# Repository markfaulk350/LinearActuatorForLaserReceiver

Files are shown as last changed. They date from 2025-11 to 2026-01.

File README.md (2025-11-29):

# Linear Actuator For Laser Receiver

# Todo
- See if we can use the DF Robot Voice Recognition to controll the whole thing. Look at the [pre-programmed keywords](https://wiki.dfrobot.com/SKU_SEN0539-EN_Gravity_Voice_Recognition_Module_I2C_UART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) to see what would work best.
- Get 4x M3 bolts for the motor. The depth is 4.5mm (0.17 in), so add the thickness of the plate. M3 x 0.5 x 8mm is best for a 0.2in plate.
- Get 3x M3 x 0.5 x 16mm bolts for the lead screw flange nut. Model the carriage so they can thread into the plastic. The flange is 0.19in thick so .6 in or 16mm is probably good. 12mm long might work but just barely, try 16mm at lowes.
- Order limit switches
- Order a linear rail. Or see if we can use the 2040 instead with a 3d printed solution.
- Order 2mm right angle pcb connector and male connector w wires
- Maybe make your own M18 adapter and put all the electronics inside it, boost converter, fuse, arduino, buck converter for arduino, etc.
- Order or make a 5mm to 3/8 coupler
- 3d print a qd mount for the laser receiver

## Custom Sensor Array vs Standard Laser Receiver on Linear Actuator
A Custom CCD or photodiode array is going to be too expensive, time consuming, and it might not work with every laser. 

On the Job, we are already moving the stick up and down, and tilting it to get the laser receiver to beep.

I propose we just hold the stick still, and have a linear actuator move the standard laser receiver until it beeps. We can tie into the laser receivers speaker wires and use that to position it perfectly. Once it's positioned, we can give the user the measurement.

### Linear Actuator
### Pros
- Cheap
- Simple to program
- Technology already exists
- Can be expanded to any length cheaply
- Can mount any laser receiver

### Cons
- Bulky
- Heavier
- Requires more power
- The physical size of the laser receiver affects the total scan area. And user needs to set the max extension so that it doesn't crash the laser receiver into the enclosure.
- Scanning is slower. 1ft per second is acceptable
  - Scanning speed largely depends on how quickly the laser receiver can detect the laser. 
- The UI is more complicated. (Calibrate, Jog, "Home", Scan)
- Different laser receivers have different speakers and signals
- If the laser receiver moves up and down, we either need to listen for the (fast, solid, slow) beeps using a microphone, or tap into the speaker wires.
- If we tap into the speaker wires, we will need to make a little radio to transmit the speaker signals to our esp32. The laser receiver will be moving up and down, we cant use a wire, it would snag or break.

# Build requirements
- Needs to scan quickly. 1ft per second is a good speed.
- Needs to move a 300g laser reeciver up and down.
- No creep. If bumped, powered off, etc. Belt drive probably wont work.
- 2 to 3 ft scan area
- Total weight under 5 pounds. Loose requirement.
- Needs to work in a dusty, hot environment.
- Encoder on stepper motor for exact position
- Maybe boost convertor for higher speeds

# Laser Receiver Dimensions
- Topcon LS-80L (NEW Model)
  - x in (Tall) | x in (Wide) | x in (Thick) | x grams (Weight)
- Topcon LS-70B (OLD Model)
  - 6.5 in (Tall) | 3 in (Wide) | 1.05 in (Thick) | 220 grams (Weight)

# Parts List
- $71 | [StepperOnline | ESS17-04](https://www.omc-stepperonline.com/ess-series-0-48nm-68oz-in-nema-17-integrated-closed-loop-stepper-servo-motor-24-36vdc-1000cpr-ess17-04)
  - [3D Model .IGS](https://www.omc-stepperonline.com/index.php?route=product/product/get_file&file=1265/ESS17-04.IGS)
  - Input Voltage: 24 - 36VDC
  - Weight: 419g
  - [SpecSheet](file:///Users/markfaulkner/Downloads/ESS17-04_07_Manual.pdf)
- $83 | [M18 HIGH OUTPUT CP3.0](https://www.milwaukeetool.com/products/48-11-1835)
  - Weight: 595g
- $8 | [M18 Adapter | Amazon](https://a.co/d/7E8KwFV)
  - Weight: 80g
- $57 | [300W Boost Converter | I7C4W008A120V-001-R | Digikey](https://www.digikey.com/en/products/detail/tdk-lambda/I7C4W008A120V-001-R/11697408)
  - Weight: 25g, 1.5 x 1.5 x 0.5 inches
  - Output Voltage: 9.6 to 48V
  - [SpecSheet](https://product.tdk.com/en/search/power/switching-power/dc-dc-converter/info?part_no=i7C4W008A120V-001-R)
- $40 | [Roton Torqspline Lead Screw, 3/8 X 1.000](https://www.roton.com/product/torqspline-steel-screw-right-60998/)
  - Weight: 368g for all 36 inches
- $20 | [Roton Torqspline Flange Nut, 3/8 X 1.000, RH, Plastic](https://www.roton.com/product/torqspline-plastic-flange-nut-right-92054/)
  - Weight: na
- $40 | [2x 2040 Aluminum V Slot 4ft | Amazon](https://a.co/d/5IGCPNE)
  - Weight: na
- $7 | [R6-2RS Bearings 3/8 ID x 7/8 OD x 9/32 | Amazon](https://a.co/d/5ckjm9j)
  - Weight: na
- $ | []()
  - Weight: na
 
## Small electronics parts list
- 47k R + 10k R Voltage divider
- 1x 0.15uf [Ceramic Capacitor](https://a.co/d/4Orx2Qe)
- [MP1584EN DC-DC Buck Converter](https://a.co/d/amErUwB)

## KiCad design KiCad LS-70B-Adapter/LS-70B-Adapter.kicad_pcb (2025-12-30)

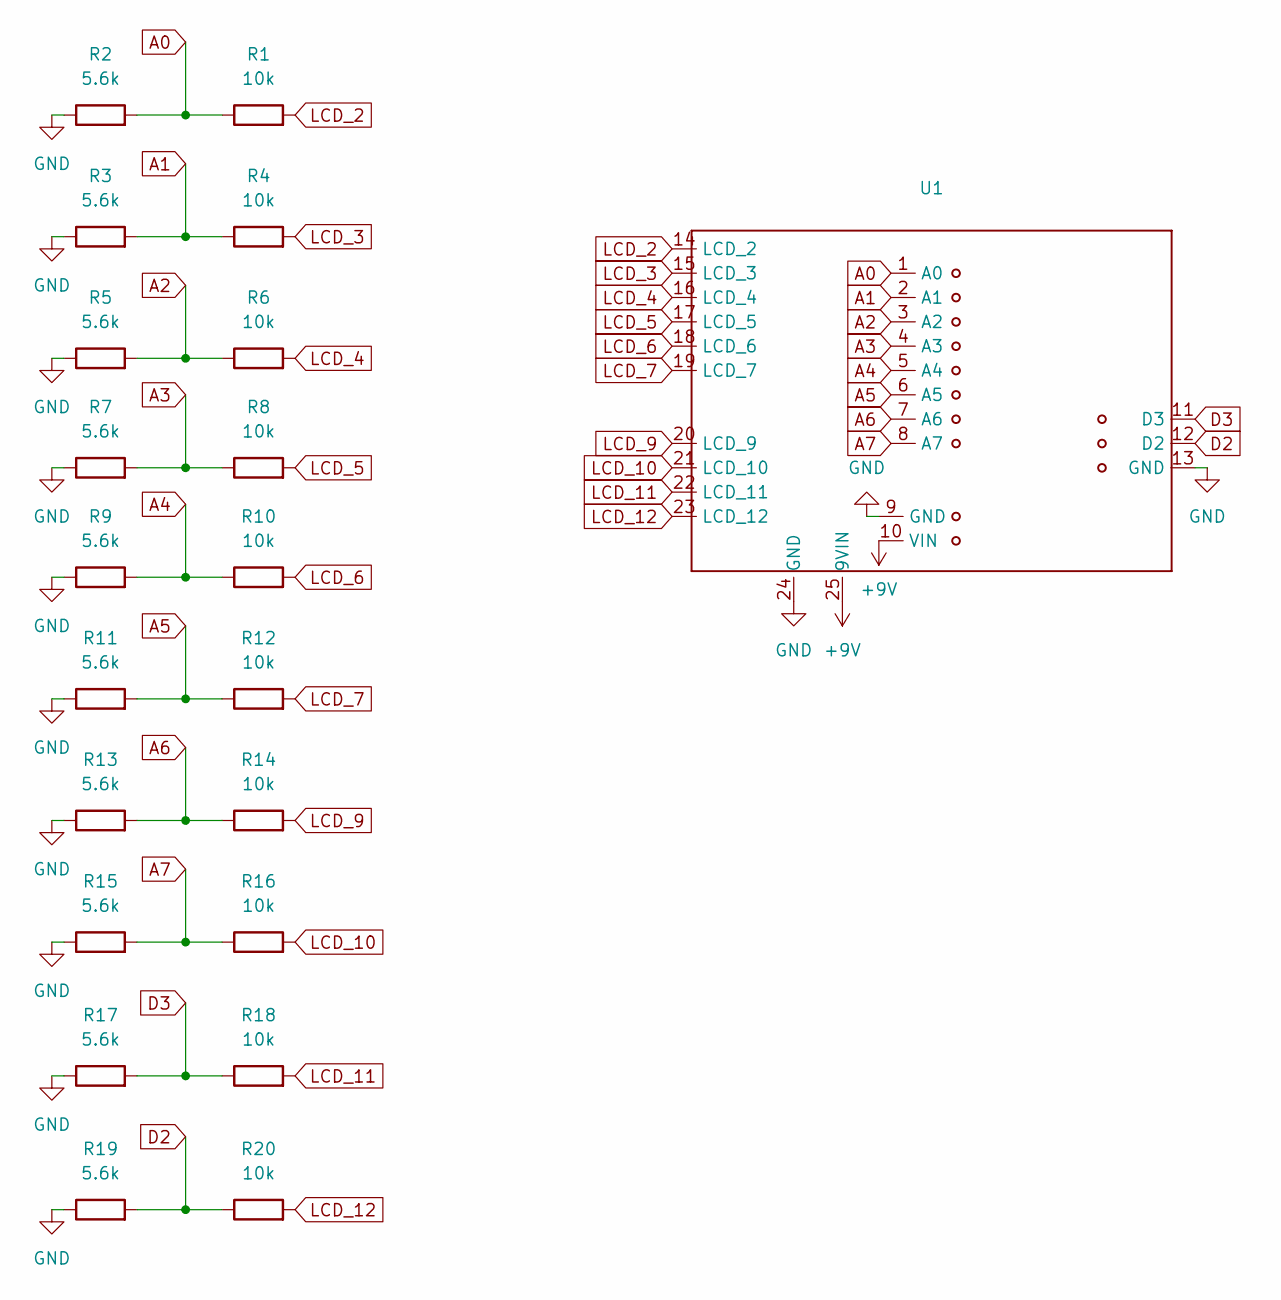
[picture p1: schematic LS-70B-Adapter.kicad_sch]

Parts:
R1, R4, R6, R8, R10, R12, R14, R16, R18, R20: 10k; R_0805_2012Metric_Pad1.20x1.40mm_HandSolder
R2, R3, R5, R7, R9, R11, R13, R15, R17, R19: 5.6k; R_0805_2012Metric_Pad1.20x1.40mm_HandSolder
U1: LS70B-Adapter

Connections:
+9V: U1.10 (VIN), U1.25 (9VIN)
A0: R1.1, R2.2, U1.1 (A0)
A1: R3.2, R4.1, U1.2 (A1)
A2: R5.2, R6.1, U1.3 (A2)
A3: R7.2, R8.1, U1.4 (A3)
A4: R9.2, R10.1, U1.5 (A4)
A5: R11.2, R12.1, U1.6 (A5)
A6: R13.2, R14.1, U1.7 (A6)
A7: R15.2, R16.1, U1.8 (A7)
D2: R19.2, R20.1, U1.12 (D2)
D3: R17.2, R18.1, U1.11 (D3)
GND: R2.1, R3.1, R5.1, R7.1, R9.1, R11.1, R13.1, R15.1, R17.1, R19.1, U1.9 (GND), U1.13 (GND), U1.24 (GND)
LCD_2: R1.2, U1.14 (LCD_2)
LCD_3: R4.2, U1.15 (LCD_3)
LCD_4: R6.2, U1.16 (LCD_4)
LCD_5: R8.2, U1.17 (LCD_5)
LCD_6: R10.2, U1.18 (LCD_6)
LCD_7: R12.2, U1.19 (LCD_7)
LCD_9: R14.2, U1.20 (LCD_9)
LCD_10: R16.2, U1.21 (LCD_10)
LCD_11: R18.2, U1.22 (LCD_11)
LCD_12: R20.2, U1.23 (LCD_12)

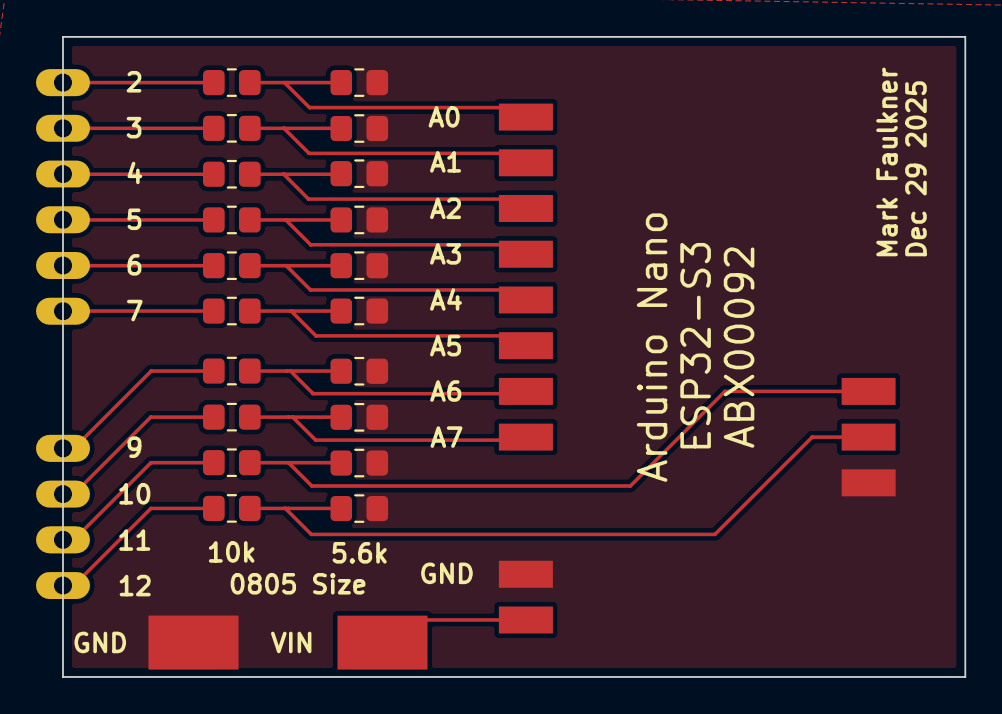
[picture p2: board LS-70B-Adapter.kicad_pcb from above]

Board: 2 copper layers, 50.1 x 35.6 mm, 21 parts (0 on the bottom side), 22 nets.

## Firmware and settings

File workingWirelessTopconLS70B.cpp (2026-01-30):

#include <Arduino.h>
#include <WiFi.h>
#include <WebServer.h>
#include <ArduinoJson.h>

WebServer server(80);

const char* ssid = "Topcon Laser";
const char* password = "12345678";

// Global transition counters — updated after each capture
int transitions_UP4 = 0;
int transitions_UP3 = 0;
int transitions_UP2 = 0;
int transitions_UP1 = 0;
int transitions_CEN = 0;
int transitions_DN1 = 0;
int transitions_DN2 = 0;
int transitions_DN3 = 0;
int transitions_DN4 = 0;
int transitions_ARR = 0;

// ─────────────────────────────────────────────
// Pin definitions
// ─────────────────────────────────────────────
constexpr int UP_BAR_4    = A2;
constexpr int UP_BAR_3    = A3;
constexpr int UP_BAR_2    = A1;
constexpr int UP_BAR_1    = A4;
constexpr int CENTER_BAR  = A5;
constexpr int DOWN_BAR_1  = A6;
constexpr int DOWN_BAR_2  = A7;
constexpr int DOWN_BAR_3  =  2;
constexpr int DOWN_BAR_4  =  3;
constexpr int TOP_ARROW   = A0;

constexpr int CAPTURE_DURATION_MS = 30;
constexpr int SAMPLE_INTERVAL_US  = 20;
constexpr int MAX_SAMPLES = 4000;

// One array per channel
uint8_t s_UP4[MAX_SAMPLES];
uint8_t s_UP3[MAX_SAMPLES];
uint8_t s_UP2[MAX_SAMPLES];
uint8_t s_UP1[MAX_SAMPLES];
uint8_t s_CEN[MAX_SAMPLES];
uint8_t s_DN1[MAX_SAMPLES];
uint8_t s_DN2[MAX_SAMPLES];
uint8_t s_DN3[MAX_SAMPLES];
uint8_t s_DN4[MAX_SAMPLES];
uint8_t s_ARR[MAX_SAMPLES];

// ─────────────────────────────────────────────
// Count number of transitions (0→1 or 1→0)
// ─────────────────────────────────────────────
int countTransitions(const uint8_t data[], uint32_t len) {
  if (len < 2) return 0;

  int flips = 0;
  uint8_t prev = data[0];

  for (uint32_t i = 1; i < len; i++) {
    if (data[i] != prev) {
      flips++;
      prev = data[i];
    }
  }

  return flips;
}

// ─────────────────────────────────────────────
// HTML: 9 horizontal bars stacked vertically (UP4 top → DN4 bottom)
// No labels, grey by default, green when active (transitions > 4)
// Updates every 200 ms
// ─────────────────────────────────────────────
const char html[] PROGMEM = R"rawliteral(
<!DOCTYPE html>
<html lang="en">
<head>
  <meta charset="UTF-8">
  <meta name="viewport" content="width=device-width, initial-scale=1.0">
  <title>Laser Receiver</title>
  <style>
    body { margin:0; height:100vh; background:#111; display:flex; justify-content:center; align-items:center; }
    .container { height:80vh; width:300px; display:flex; flex-direction:column; gap:4px; }
    .bar { flex:1; background:#444; border-radius:6px; transition:background 0.1s; }
    .bar.active { background:#3eff51; }
  </style>
</head>
<body>
  <div class="container">
    <div class="bar" id="bar-UP4"></div>
    <div class="bar" id="bar-UP3"></div>
    <div class="bar" id="bar-UP2"></div>
    <div class="bar" id="bar-UP1"></div>
    <div class="bar" id="bar-CEN" style="border: 2px solid red;"></div>
    <div class="bar" id="bar-DN1"></div>
    <div class="bar" id="bar-DN2"></div>
    <div class="bar" id="bar-DN3"></div>
    <div class="bar" id="bar-DN4"></div>
  </div>

  <script>
    const bars = {
      "UP4": document.getElementById("bar-UP4"),
      "UP3": document.getElementById("bar-UP3"),
      "UP2": document.getElementById("bar-UP2"),
      "UP1": document.getElementById("bar-UP1"),
      "CEN": document.getElementById("bar-CEN"),
      "DN1": document.getElementById("bar-DN1"),
      "DN2": document.getElementById("bar-DN2"),
      "DN3": document.getElementById("bar-DN3"),
      "DN4": document.getElementById("bar-DN4")
    };

    function update() {
      fetch('/data')
        .then(r => r.json())
        .then(data => {
          Object.keys(data).forEach(key => {
            if (bars[key]) {
              if (data[key] > 4) {
                bars[key].classList.add('active');
              } else {
                bars[key].classList.remove('active');
              }
            }
          });
        })
        .catch(e => console.error(e));
    }

    update();
    setInterval(update, 50);
  </script>
</body>
</html>
)rawliteral";

// ─────────────────────────────────────────────
void setup() {
  Serial.begin(2000000);
  delay(200);

  pinMode(UP_BAR_4,   INPUT);
  pinMode(UP_BAR_3,   INPUT);
  pinMode(UP_BAR_2,   INPUT);
  pinMode(UP_BAR_1,   INPUT);
  pinMode(CENTER_BAR, INPUT);
  pinMode(DOWN_BAR_1, INPUT);
  pinMode(DOWN_BAR_2, INPUT);
  pinMode(DOWN_BAR_3, INPUT);
  pinMode(DOWN_BAR_4, INPUT);
  pinMode(TOP_ARROW,  INPUT);

  WiFi.softAP(ssid, password);
  Serial.print("Hotspot: ");
  Serial.print(ssid);
  Serial.print(" | IP: ");
  Serial.println(WiFi.softAPIP());

  server.on("/", []() {
    server.send_P(200, "text/html", html);
  });

  server.on("/data", []() {
    JsonDocument doc;
    doc["UP4"] = transitions_UP4;
    doc["UP3"] = transitions_UP3;
    doc["UP2"] = transitions_UP2;
    doc["UP1"] = transitions_UP1;
    doc["CEN"] = transitions_CEN;
    doc["DN1"] = transitions_DN1;
    doc["DN2"] = transitions_DN2;
    doc["DN3"] = transitions_DN3;
    doc["DN4"] = transitions_DN4;

    String json;
    serializeJson(doc, json);
    server.send(200, "application/json", json);
  });

  server.begin();
}

// ─────────────────────────────────────────────
void loop() {
  server.handleClient();

  static uint32_t lastStart = 0;
  if (millis() - lastStart < 100) return;  // capture every 0.1 second
  lastStart = millis();

  uint32_t tStart = micros();
  uint32_t tEnd   = tStart + CAPTURE_DURATION_MS * 1000UL;

  uint32_t count = 0;
  uint32_t nextSampleTime = tStart;

  while (micros() < tEnd && count < MAX_SAMPLES) {
    while (micros() < nextSampleTime) {}  // wait

    s_UP4[count] = digitalRead(UP_BAR_4);
    s_UP3[count] = digitalRead(UP_BAR_3);
    s_UP2[count] = digitalRead(UP_BAR_2);
    s_UP1[count] = digitalRead(UP_BAR_1);
    s_CEN[count] = digitalRead(CENTER_BAR);
    s_DN1[count] = digitalRead(DOWN_BAR_1);
    s_DN2[count] = digitalRead(DOWN_BAR_2);
    s_DN3[count] = digitalRead(DOWN_BAR_3);
    s_DN4[count] = digitalRead(DOWN_BAR_4);
    s_ARR[count] = digitalRead(TOP_ARROW);

    count++;
    nextSampleTime += SAMPLE_INTERVAL_US;
  }

  // Update global transition counts
  transitions_UP4 = countTransitions(s_UP4, count);
  transitions_UP3 = countTransitions(s_UP3, count);
  transitions_UP2 = countTransitions(s_UP2, count);
  transitions_UP1 = countTransitions(s_UP1, count);
  transitions_CEN = countTransitions(s_CEN, count);
  transitions_DN1 = countTransitions(s_DN1, count);
  transitions_DN2 = countTransitions(s_DN2, count);
  transitions_DN3 = countTransitions(s_DN3, count);
  transitions_DN4 = countTransitions(s_DN4, count);
  transitions_ARR = countTransitions(s_ARR, count);
}

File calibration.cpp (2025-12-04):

// This code homes, goes up to x then steps down 4 steps (0.01in) at a time logging the current Beep status of OFF, FAST, SOLID, SLOW
// This code is used as a referece point for testing other code.
// This also tells us the range of each area of the sensor on the laser receiver

#include <AccelStepper.h>

// ───── Stepper Motor ─────
#define MF_PLUS_PIN 11        // for alarm clearing
#define PULSE_PIN 12
#define DIR_PIN   13
#define ALARM_PIN 14

#define PULSES_PER_REVOLUTION 400

// ───── POSITIONS (hard-coded in inches) ─────
const long POS_HOME     = 0;                                 // 0 inches
const long POS_MIDDLE   = 17L * PULSES_PER_REVOLUTION;       // 17 inches
const long POS_FAR      = 34L * PULSES_PER_REVOLUTION;       // 34 inches
const long ONE_INCH     = 1L  * PULSES_PER_REVOLUTION;       // 1 inch step

// ───── Motor Speed ─────
const long MAX_SPEED_INCHES_PER_SECOND = 6L;
const long MAX_ACCELERATION_PULSES_PER_SECOND = 60L;

const int PIEZO_PIN = 1;
const int SAMPLE_RATE_MS = 5;
const int WINDOW_SIZE = 250 / SAMPLE_RATE_MS;  // 50 samples

int buffer[WINDOW_SIZE];
int idx = 0;
unsigned long last = 0;


AccelStepper stepper(AccelStepper::DRIVER, PULSE_PIN, DIR_PIN);

void setup() {
  Serial.begin(2000000);
  analogReadResolution(12);

  Serial.println("=== RANGE TEST STARTING ===");

  pinMode(ALARM_PIN, INPUT_PULLUP);
  pinMode(MF_PLUS_PIN, OUTPUT);

  // Initialize stepper
  stepper.setMaxSpeed(MAX_SPEED_INCHES_PER_SECOND * PULSES_PER_REVOLUTION);
  stepper.setAcceleration(MAX_ACCELERATION_PULSES_PER_SECOND * PULSES_PER_REVOLUTION);
  stepper.setCurrentPosition(POS_HOME);  // Assume we start at home

 // This will reverse at 1 inch per second and Home automatically. You can comment this out and call it manually if you want using a voice command
  Serial.println("=== HOMING BY STALLING ===");
  homeByStall();

  delay(5000);

  // Move to 34 inches;
  Serial.println("=== MOVE TO 34 IN ===");
  safeMoveTo(25L * PULSES_PER_REVOLUTION);

  delay(5000);

  scanDown();

  Serial.println("=== FINISHED ===");

}

void safeMoveTo(long target) {
  target = constrain(target, POS_HOME, POS_FAR);  // Hard soft limits
  stepper.moveTo(target);
  while (stepper.distanceToGo() != 0) stepper.run();
}


void instantStop() {
  Serial.println("EMERGENCY STOP!");

  long currentPos = stepper.currentPosition();        // Save the exact position

  // Cancel motion instantly but preserve real position
  stepper.setCurrentPosition(currentPos);     // Keep the real position we just saved
  stepper.moveTo(currentPos);                 // Cancel any remaining travel
  stepper.setSpeed(0);                        // Stop generating pulses

  Serial.println("Motor stopped — position preserved for distance calc");


  long stepsFromCenter = currentPos - 6800;           // Subtract 6800 steps aka 17 inches
  float inchesFromCenter = (float)stepsFromCenter / 400.0;  // Convert to revolutions

  // ───── Print everything nicely ─────
  Serial.println("─────────────────────────────");
  Serial.print("Current Position (pulses): ");
  Serial.println(currentPos);

  Serial.print("Steps from Center (after -6800): ");
  Serial.println(stepsFromCenter);

  Serial.print("Distance from Center: ");
  Serial.print(inchesFromCenter, 3);
  Serial.println(" inches");
  Serial.println("─────────────────────────────");

  digitalWrite(LED_BUILTIN, HIGH); // Why is this here ??
}

void clearMotorAlarm() {
  digitalWrite(MF_PLUS_PIN, HIGH); delay(200);
  digitalWrite(MF_PLUS_PIN, LOW);  delay(200);
}

void homeByStall() {
  Serial.println("Re-homing by stall...");
  // Set speed and acceleration to low value like 1 inch per second
  // Use Negative value to go backwards
  stepper.setSpeed(-1 * PULSES_PER_REVOLUTION);
  while (digitalRead(ALARM_PIN) == HIGH) {
    stepper.runSpeed();
    delay(2);
  }
  clearMotorAlarm();
  stepper.stop();
  stepper.setCurrentPosition(0);
  // POS_HOME = 0; Why did grok do this?
  Serial.println("Homed — position = 0");
}

// Returns a String with the beep status
// String analyzePiezoData(float piezoData[50]) {
//   // Convert float voltages to binary 1 / 0 (same threshold you use)
//   int binary[50];
//   for (int i = 0; i < 50; i++) {
//     binary[i] = (piezoData[i] > 0.2f) ? 1 : 0;
//   }

//   // Find longest run of 1's
//   int longestOnes = 0;
//   int current = 0;
//   for (int i = 0; i < 50; i++) {
//     if (binary[i] == 1) {
//       current++;
//       if (current > longestOnes) longestOnes = current;
//     } else {
//       current = 0;
//     }
//   }

//   // Your exact rules
//   if (longestOnes == 0)                  return "100% OFF";
//   if (longestOnes == 50)                     return "100% SOLID (on-grade)";
//   if (longestOnes <= 9)                  return "OFF";
//   if (longestOnes <= 14)                 return "FAST (too high)";
//   if (longestOnes <= 21)                 return "GREY AREA";
//   if (longestOnes <= 26)                 return "SLOW (too low)";
//   return "SOLID (on-grade)";
// }

String analyzePiezoData(float piezoData[50]) {
  int binary[50];
  for (int i = 0; i < 50; i++) {
    binary[i] = (piezoData[i] > 0.2f) ? 1 : 0;
  }

  int longestOnes = 0;
  int current = 0;
  for (int i = 0; i < 50; i++) {
    if (binary[i] == 1) {
      current++;
      if (current > longestOnes) longestOnes = current;
    } else {
      current = 0;
    }
  }

  String base;
  if (longestOnes == 0)                  base = "OFF"; // 100% OFF
  else if (longestOnes == 50)            base = "SOLID"; // 100% SOLID (on-grade)
  else if (longestOnes <= 9)             base = "OFF"; // OFF
  else if (longestOnes <= 12)            base = "FAST"; // FAST (too high)
  else if (longestOnes <= 21)            base = "SLOW"; // GREY AREA
  else if (longestOnes <= 26)            base = "SLOW"; // SLOW (too low)
  else                                   base = "SOLID"; // SOLID (on-grade)

  // ← Append the count of longest run of 1's
  return base + " [" + String(longestOnes) + "]";
}
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
